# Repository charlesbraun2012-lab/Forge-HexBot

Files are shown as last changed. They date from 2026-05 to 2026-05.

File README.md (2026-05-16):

# Forge-HexBot
HexBot V2 (yes there was a v1 😭) is a mostly 3d printed 3d printer (only uses screws and threaded inserts but for v3 I plan to make it all press fit). This project is powered by: Forge, WhamBamSystems, and LDO Motors. This uses the open scource MKS tinybee board with TMC2209 with wifi integration. I plan to devlop a web app to utlise remote printing and controll. Additionally I plan to make an AMS style system that will be able to change colours wirelessly. (That is a seprate project) I made this project because I learned so much from V1 that I feel it wouldnt be right to not make anouther version.

V1:


V2 CAD:

Forge Printer _ V2 Assembily - Google Chrome 5_16_2026 5_11_53 PM

Wiring Diagram:

Untitled presentation (3)

Z-Axis

    Z-Axis motor $17 KB-3D Link
  
    M3 Nuts and bolts $10 Amazon Link
  
X-Axis

    E3D V6 Hot End $14 E3D V6 Hot End Link
  
    Extruder motor $17 KB-3D Link
  
    Extruder $6 Amazon Link
  
    X-Axis Motor$17KB-3D Link
  
    Pulleys $7 Amazon link
  
Y-Axis

    Y-axis motor $17 KB-3D Link
  
    Grease $8 Amazon Link
  
Electronics

    MKS TinyBee + screen + tmc drivers $59 Amazon Link
  
    Limit Switch $5 Amazon Link
  
    Wire Crimper & Connectors $30 Amazon Link
  
    Power supply $18 Amazon Link
  
    22 AWG wires $7 Amazon Link

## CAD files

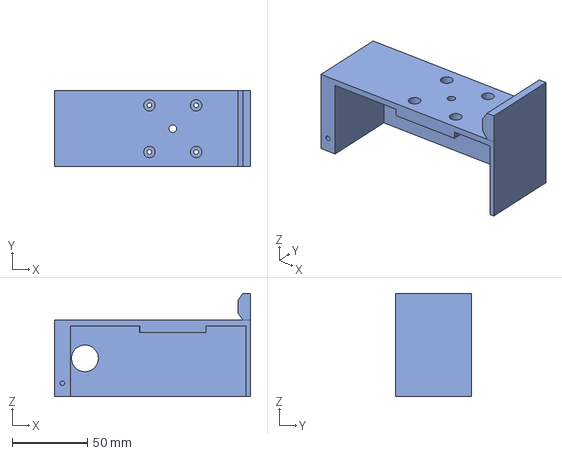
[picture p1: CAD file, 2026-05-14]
CAD/y-axis motor mount.step
130.1 x 50.3 x 68.6 mm

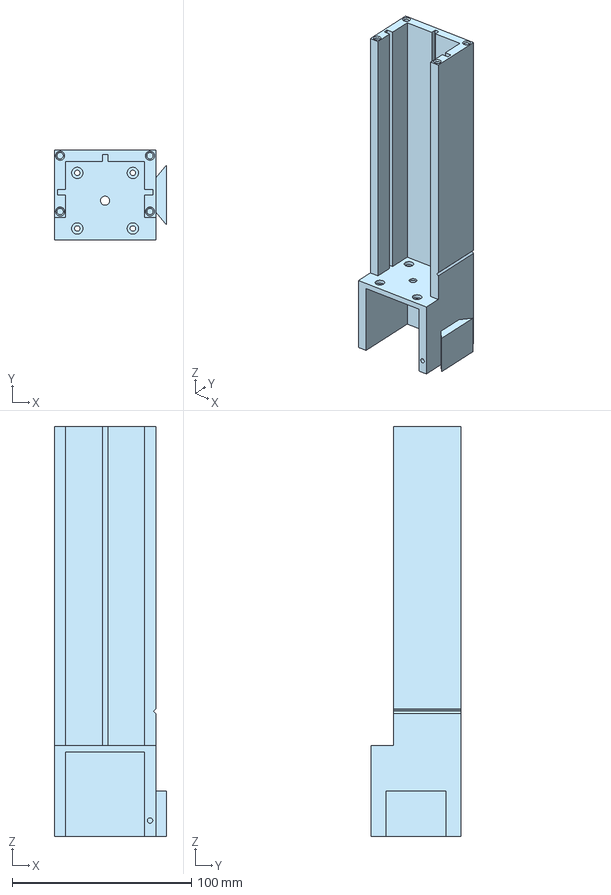
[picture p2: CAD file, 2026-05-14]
CAD/Z-Tower.step
62.7 x 50.3 x 228.6 mm

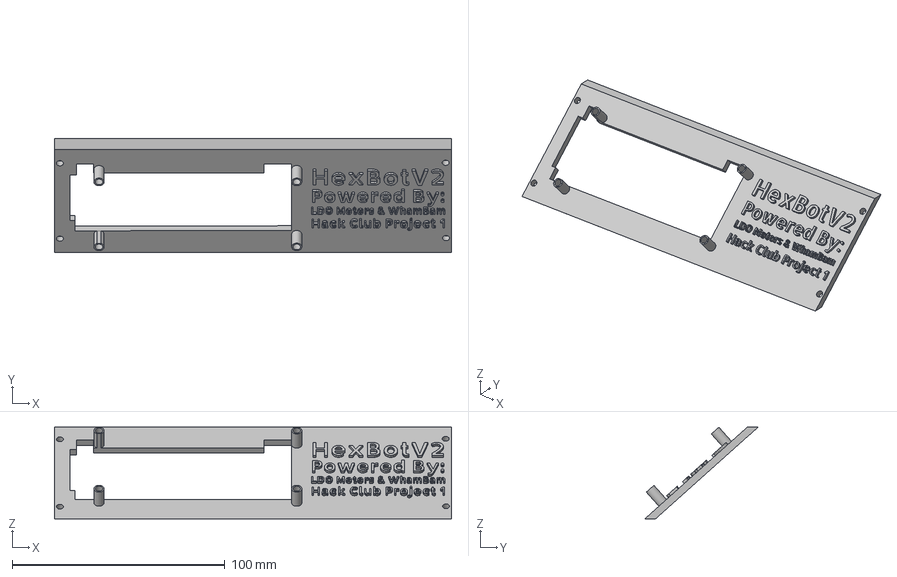
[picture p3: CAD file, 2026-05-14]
CAD/Front Base.step
186.7 x 53.4 x 43.2 mm

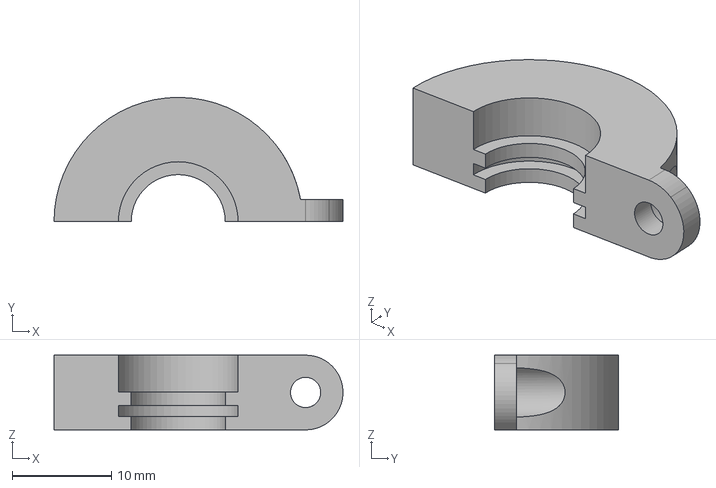
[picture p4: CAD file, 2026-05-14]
CAD/Extruder clamp.step
29.1 x 12.5 x 7.54 mm

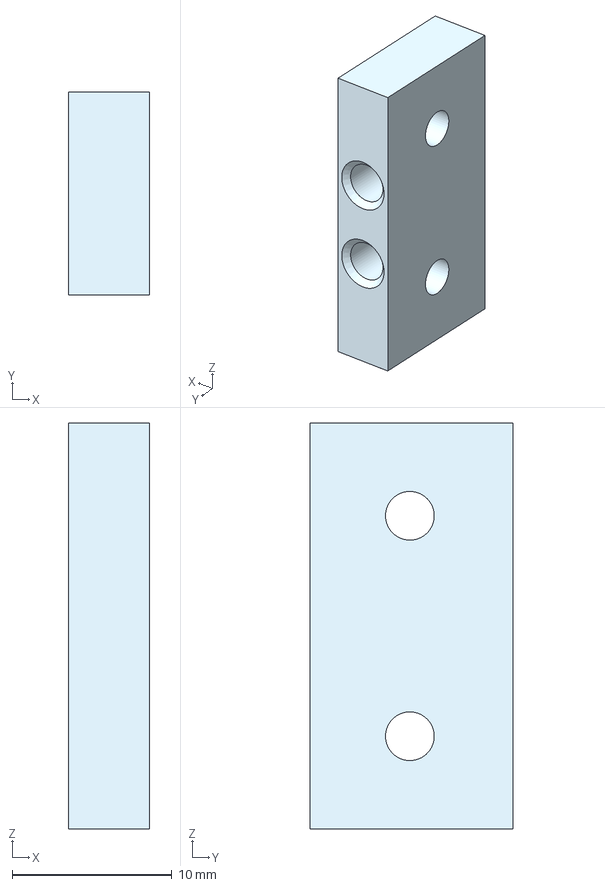
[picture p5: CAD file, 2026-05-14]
CAD/x-axis Idler tensioner.step
5.08 x 12.7 x 25.4 mm

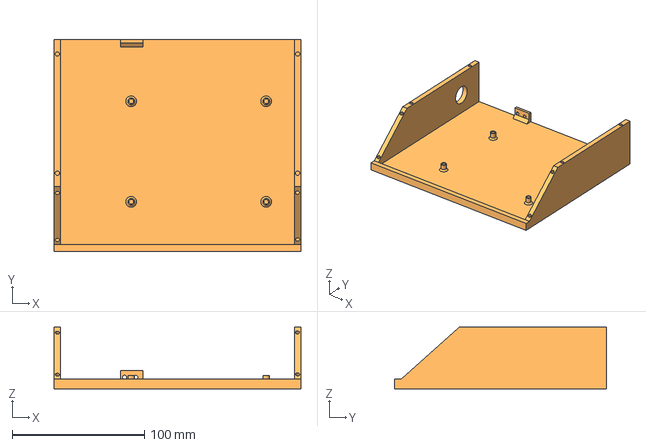
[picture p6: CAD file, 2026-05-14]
CAD/Base.step
186.7 x 160.0 x 46.9 mm

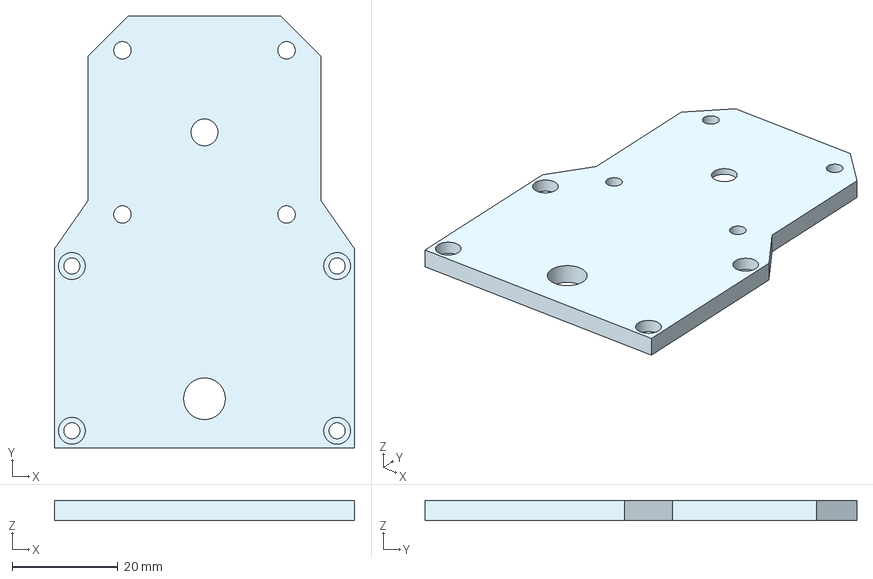
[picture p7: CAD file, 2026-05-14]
CAD/z-tower cap + extruder mount.step
56.6 x 81.6 x 3.81 mm

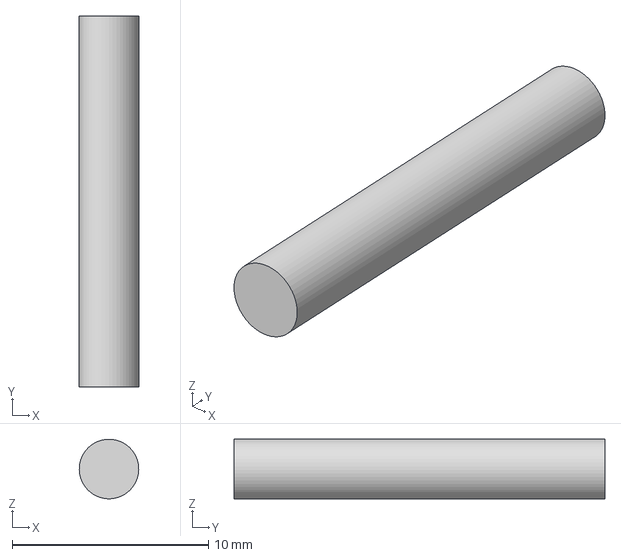
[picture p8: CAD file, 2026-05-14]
CAD/x-axis roller pin.step
3.04 x 18.9 x 3.04 mm

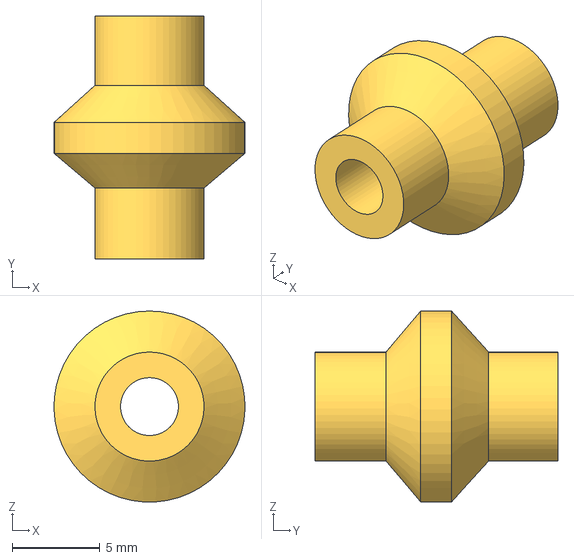
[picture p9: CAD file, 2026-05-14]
CAD/X-axis roller.step
10.9 x 13.8 x 10.9 mm

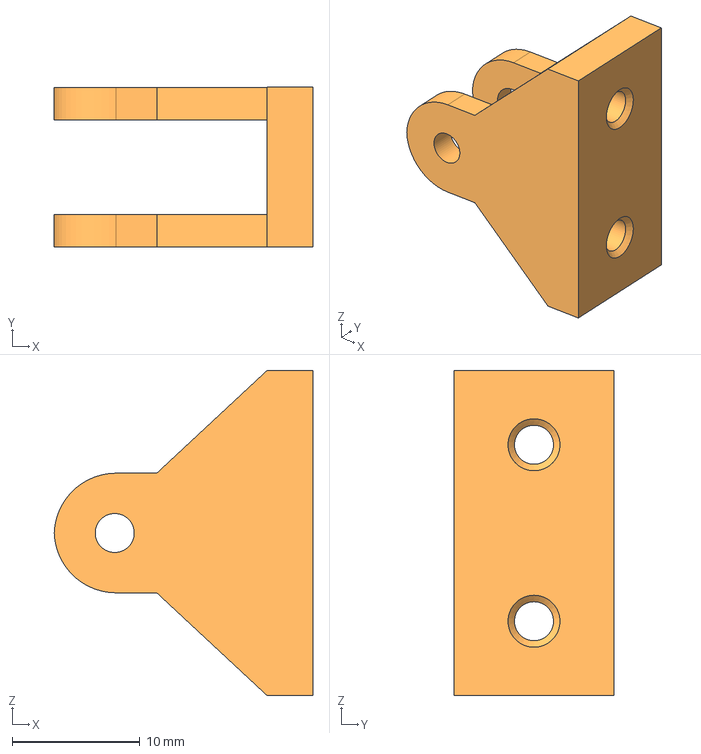
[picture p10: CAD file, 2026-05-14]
CAD/X-axis idler holder.step
20.2 x 12.5 x 25.4 mm

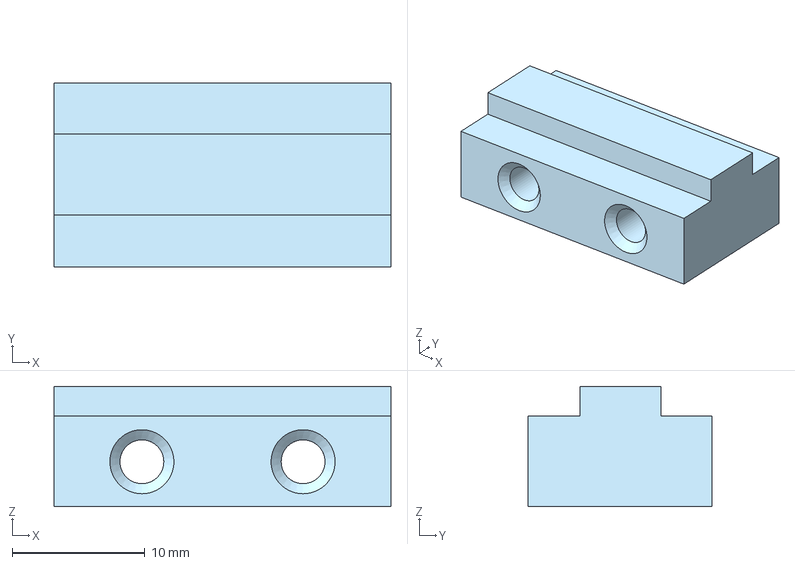
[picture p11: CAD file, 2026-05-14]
CAD/X-axis carriage bottom strengthener.step
25.4 x 13.9 x 9.05 mm

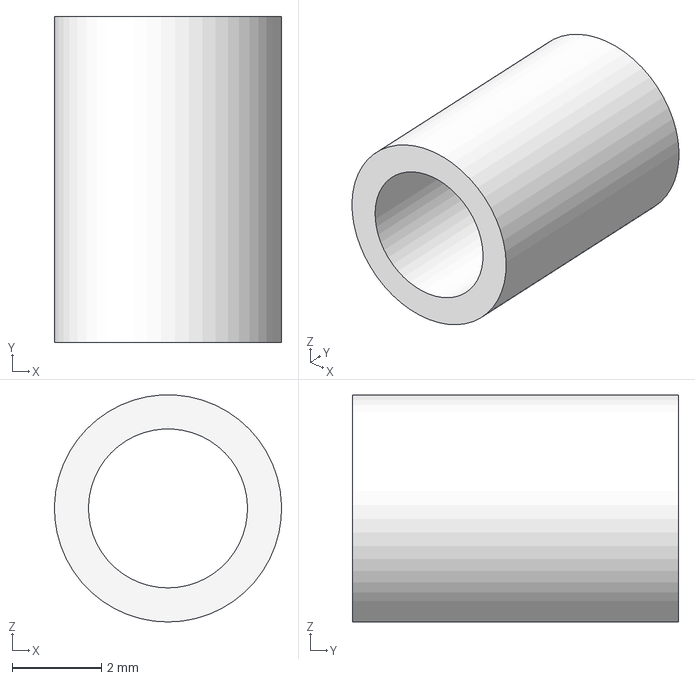
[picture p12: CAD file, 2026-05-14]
CAD/Idler pulley.step
5.08 x 7.29 x 5.08 mm

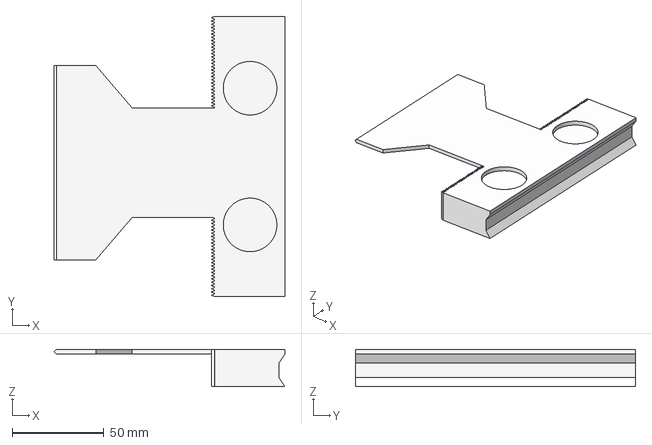
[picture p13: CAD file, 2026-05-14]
CAD/y-axis bed plate.step
125.8 x 152.5 x 20.3 mm

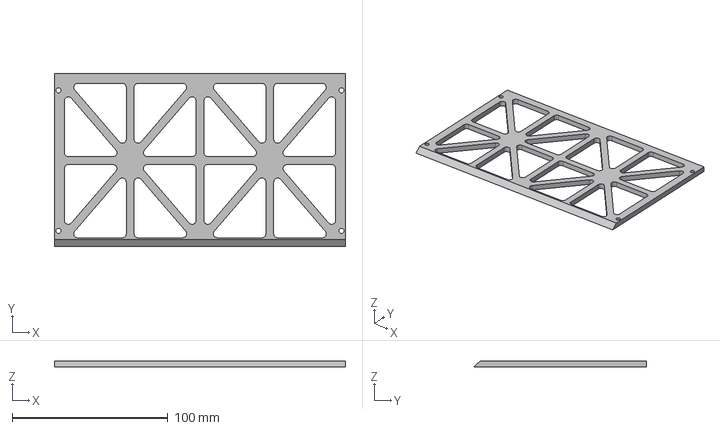
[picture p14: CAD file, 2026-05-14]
CAD/Base Top.step
186.7 x 111.0 x 3.94 mm

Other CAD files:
CAD/x-axis belt plate.step
CAD/Extruder holder plate (x carrage).step
CAD/y-axis gear.step
CAD/X-Axis arm.step
CAD/Z-Axis Nut - carrage.step
CAD/Z-tower lead screw.step

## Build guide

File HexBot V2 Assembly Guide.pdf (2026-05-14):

# HexBot V2 Assembly Guide

## Open Source created by Charles Braun under MIT License

## Z-Axis

Parts Needed:

1x lead screw (Printed at 96% scale on x and y axis, print test piece to find optimal sale)

1 Lead Screw housing

1x Lead Screw bearing block

1x Lead screw cap & extruder mount

1x Stepper Motor (Nema 17)

9x M3 heat set inserts

8x M3 screws

## Step 1:

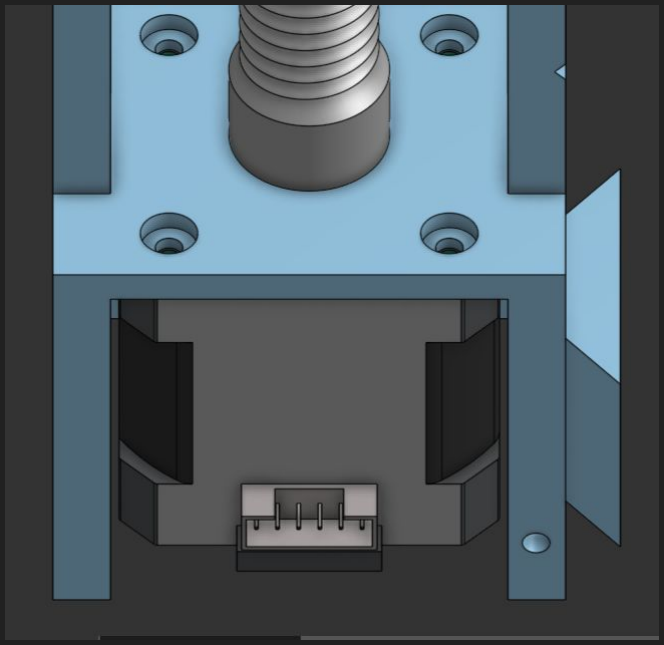
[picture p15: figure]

Take the Nema 17 and screw it in.

Make sure the connector/wires are facing out.

## Step 2:

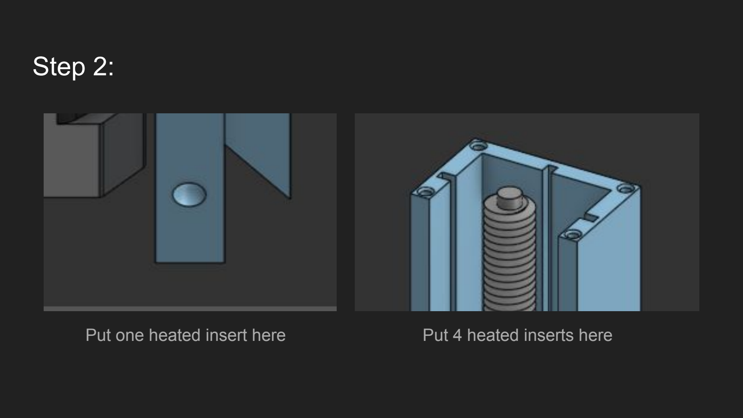
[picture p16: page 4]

Put one heated insert here | Put 4 heated inserts here

## Step 3:

Slide Lead screw onto the
Nema 17 shaft.

## Step 4:

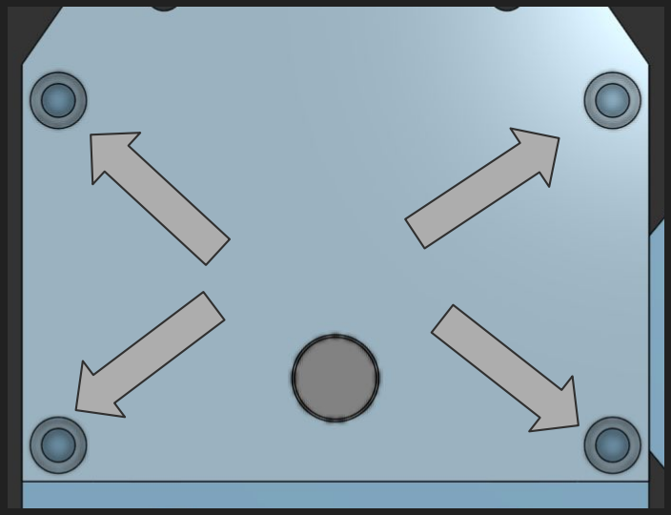
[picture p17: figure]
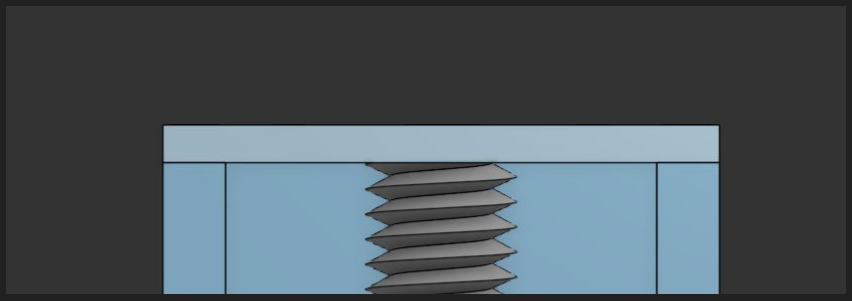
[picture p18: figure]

Put an M3 screw into the threaded insert with the lead screw top in the middle of the screw head and the insert.

## Step 5:

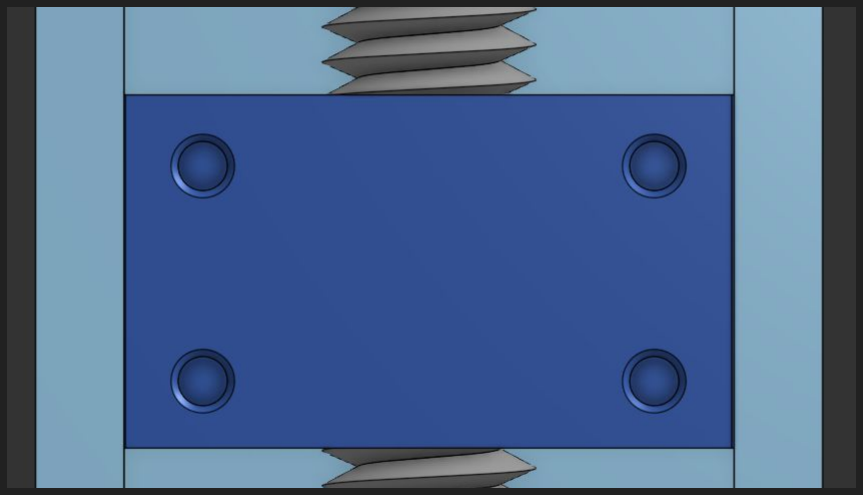
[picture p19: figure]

Put one M3 heat insert in each of the 4 holes

## Step 6:

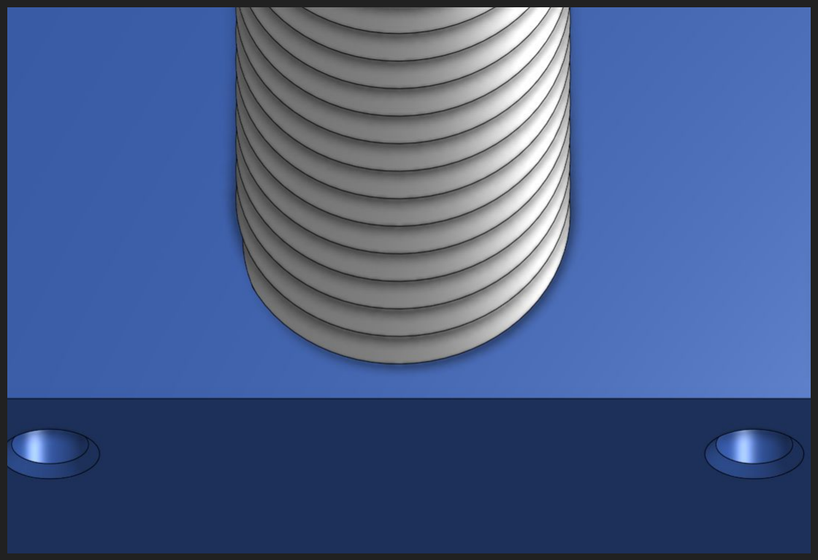
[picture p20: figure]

Screw the lead screw into the lead screw bearing block

## X-Axis

Parts Needed:

1x Main Arm

1x Idler Holder

1x Idler tensioner

1x Belt Plate

1x Hotend Plate

2x rollers

1x bottom holder

1x Stepper Motor (Nema 17)

10x M3 heat set inserts

8x M3 screws

1x pulley & idler

1x 1 Meter GT2 timing belt

2x Pins for rollers

## Step 1:

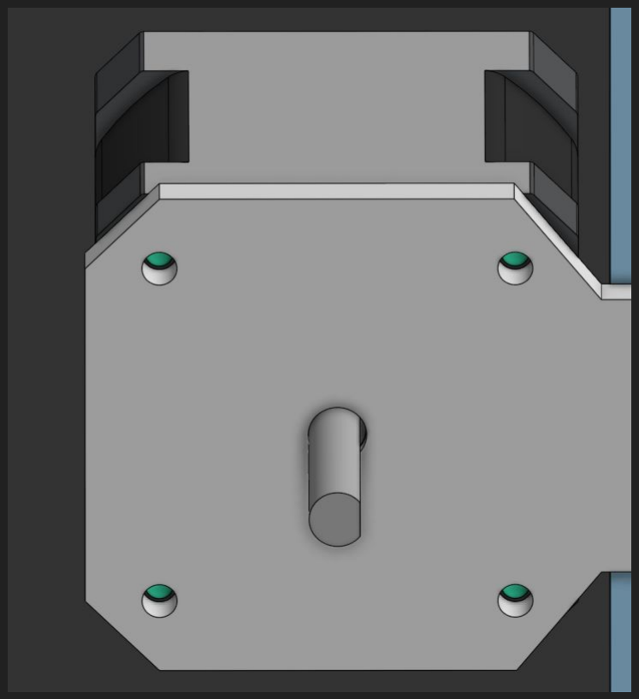
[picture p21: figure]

Screw the Nema 17 into the far left end of the arm

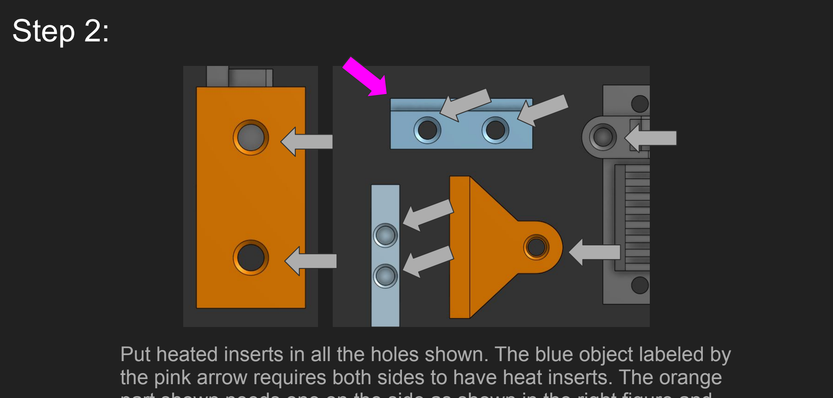
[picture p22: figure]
Step 2:

Put heated inserts in all the holes shown. The blue object labeled by the pink arrow requires both sides to have heat inserts. The orange part shown needs one on the side as shown in the right figure and two in the back as shown in the left.

## Step 3:

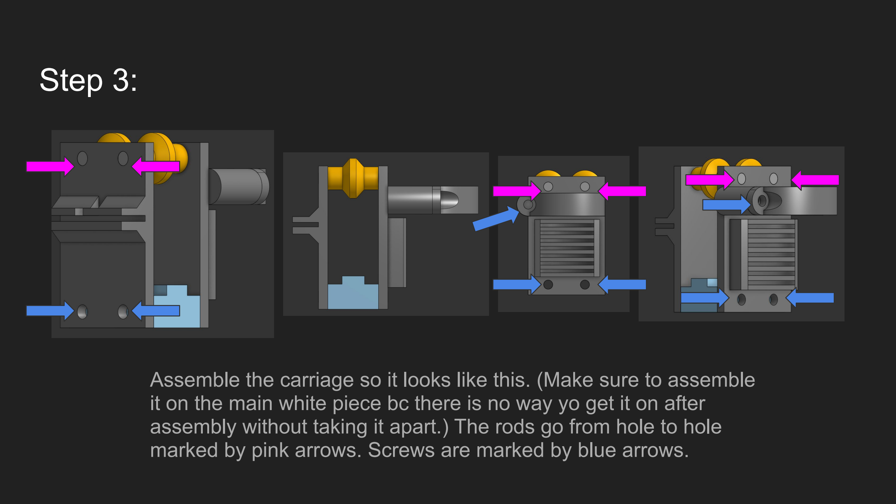
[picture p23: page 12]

Assemble the carriage so it looks like this. (Make sure to assemble it on the main white piece bc there is no way yo get it on after assembly without taking it apart.) The rods go from hole to hole marked by pink arrows. Screws are marked by blue arrows.

## Step 4:

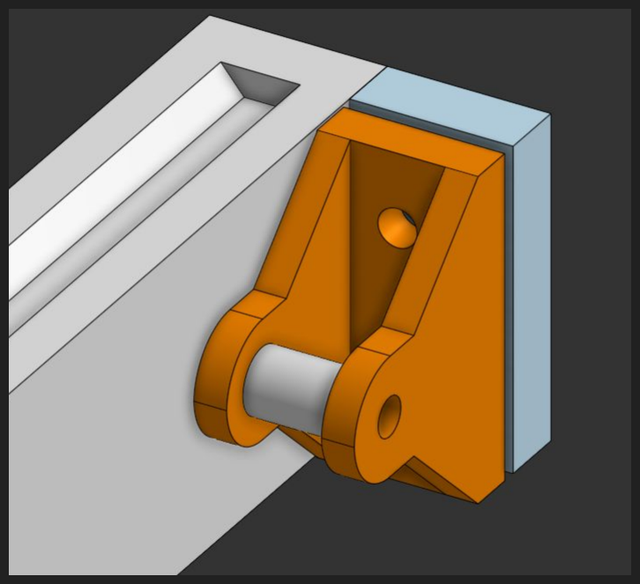
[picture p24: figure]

Take the idler holder (orange) and put the idler (White tube) in the middle of the hole. Put a M3 screw into the front side and screw until it reaches the heat insert in the back side.

Take the idler tensioner
block (light blue) and put a screw through the rail
(white)

## Step 5:

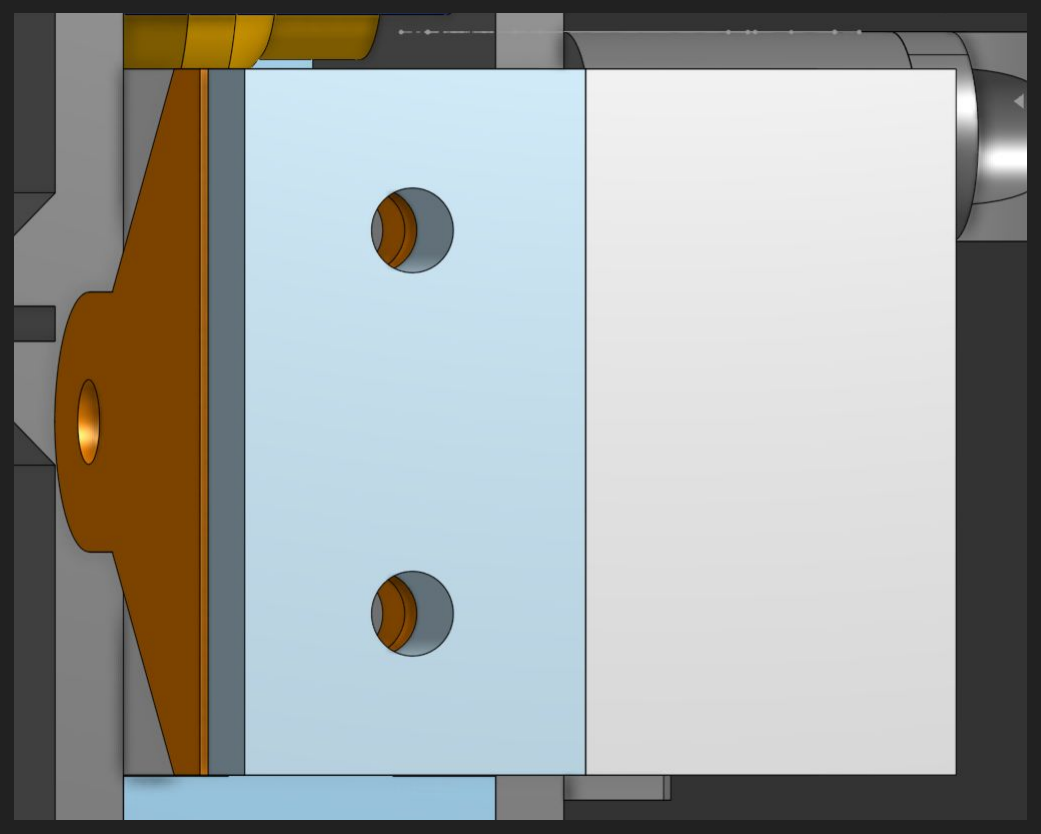
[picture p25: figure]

Put a screw through each hole on the light blue part and make sure it touches the threaded insert in the orange part. To tension the belt just turn the screws right.

## Step 6:

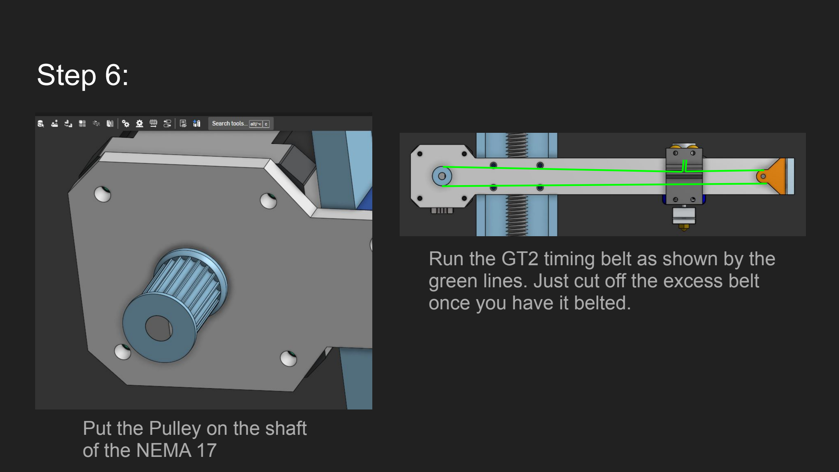
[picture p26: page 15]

Put the Pulley on the shaft of the NEMA 17

Run the GT2 timing belt as shown by the green lines. Just cut off the excess belt once you have it belted.

Y-Axis | Parts Needed:

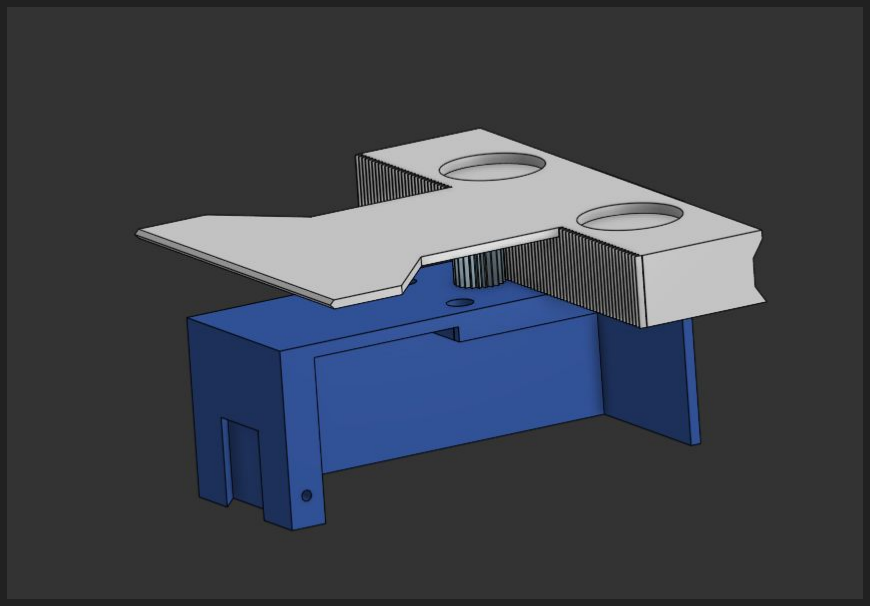
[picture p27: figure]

| 1x Y-Motor mount
| 1x Bed Platform
| 1x Gear
| 1x Nema 17
| 1x heat insert
| 1x 165x165 build plate (can be 3d printed as long as painters tape is applied to the top)
| Optional :
| 2x Magnets less than 0.11 in tall

## Step 1:

Screw the NEMA 17 in.
(Make sure the screws are
either flush or below the
top because that can lead
to interference.

## Step 2:

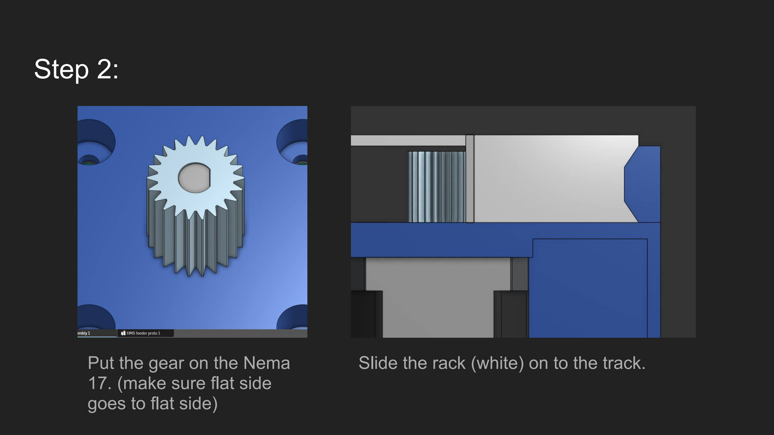
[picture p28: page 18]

Put the gear on the Nema
17. (make sure flat side
goes to flat side)

Slide the rack (white) on to the track.

## Step 3: (Optional)

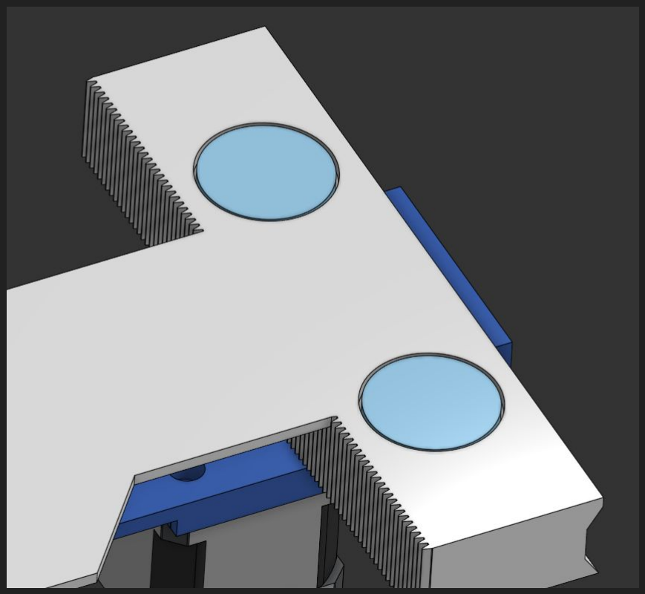
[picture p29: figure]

Put 2 magnets in the slots. No taller than 0.11 in (2.8mm) and no wider than 1.1 in (28mm) just use hot glue or sum to attach.

Base | Parts Needed:
| 1x front plate
| 1x top plate
| 1x base tray
| 1x MKS Mini12864 V3 (screen)
| 1x MKS TinyBee V1.0 (Board)
| 16x heat insert

## Step 1:

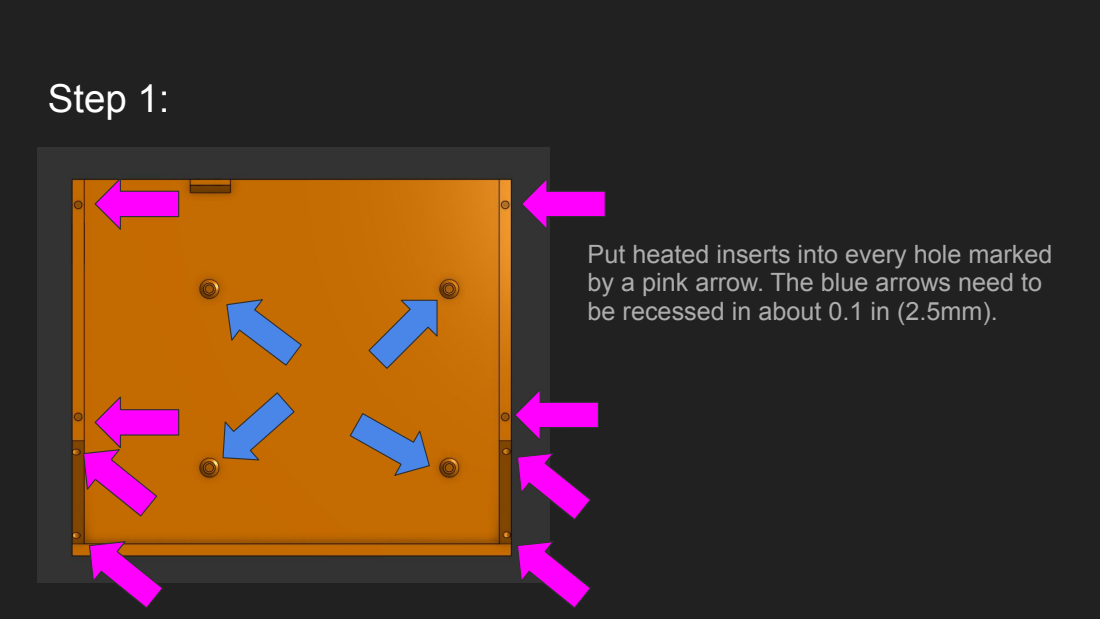
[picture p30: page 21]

Put heated inserts into every hole marked
by a pink arrow. The blue arrows need to
be recessed in about 0.1 in (2.5mm).

## Step 2:

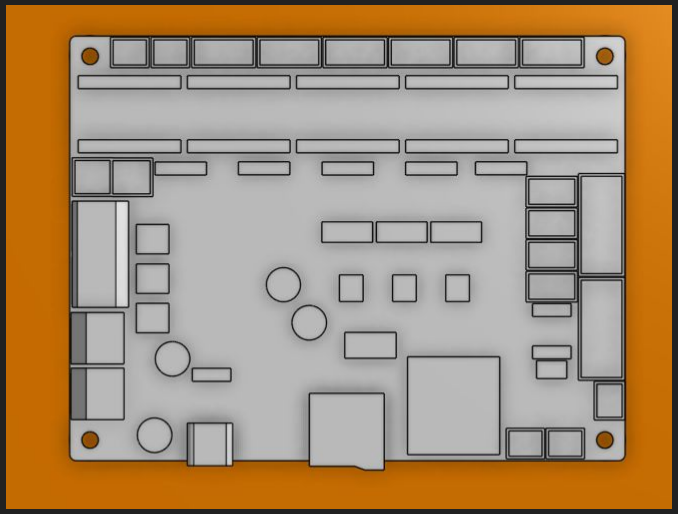
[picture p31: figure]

Put the MKS tinybee on. (Do Not overtighten bc I dont want u to break the board)

## Step 3:

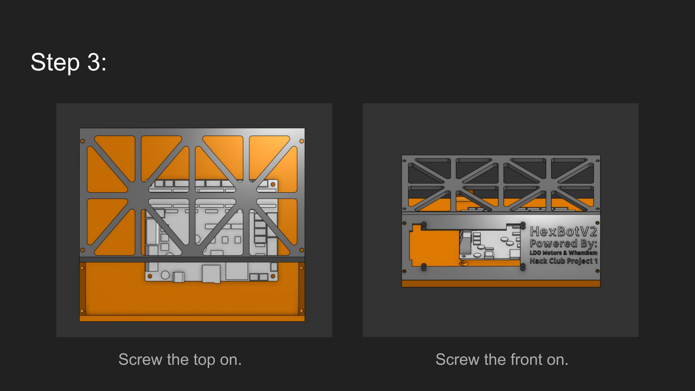
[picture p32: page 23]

Screw the top on. | Screw the front on.

## Step 4:

Put heated inserts where the blue arrows are

Screw the screen in (do not overtighten)

## Extruder

Parts Needed:

1x Nema 17

1x Bowden extruder (Ender 3) kit

1x Bowden tubing

## Step 1:

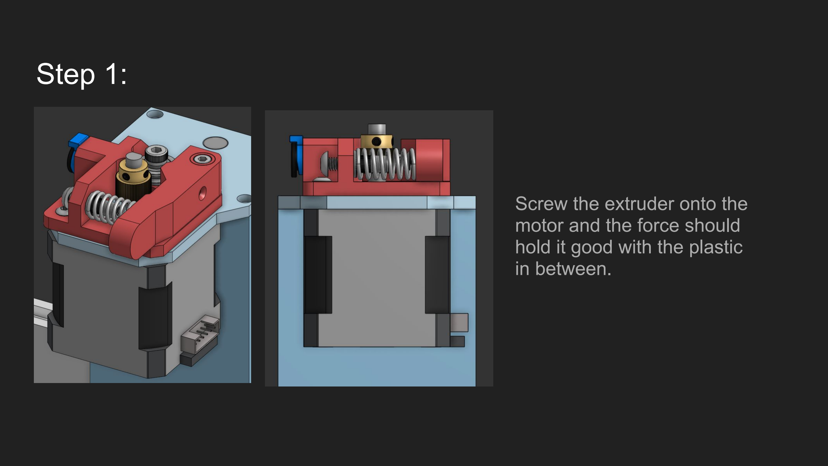
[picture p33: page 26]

Screw the extruder onto the motor and the force should hold it good with the plastic in between.

## Step 2:

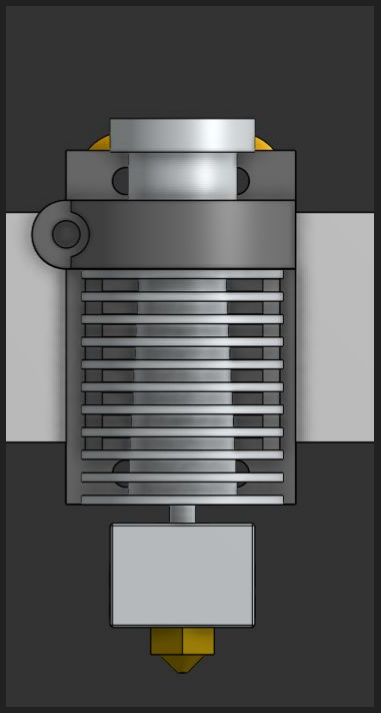
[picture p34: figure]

Screw the screw marked by
the blue arrow to clamp in the hotend.

## Final assembly

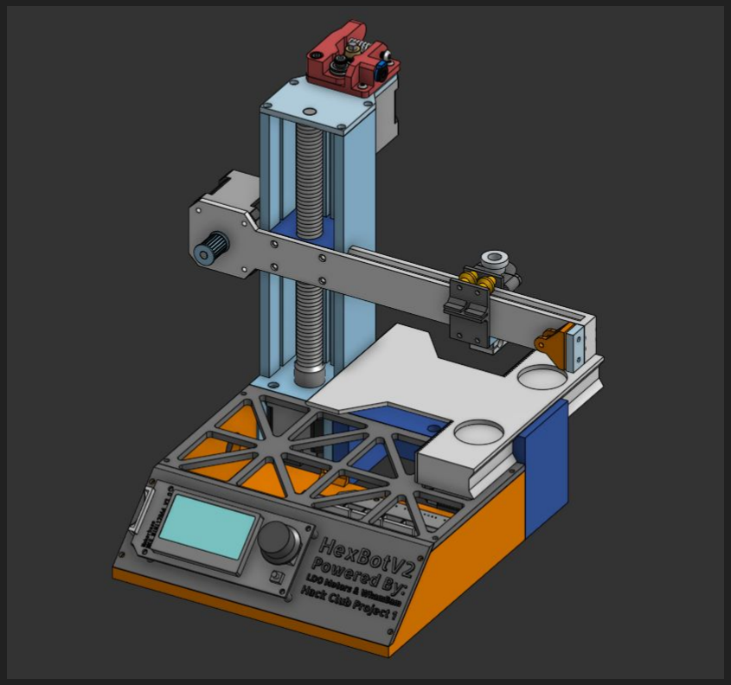
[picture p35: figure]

Parts Needed:

1x X-axis

1x Z-Tower

1x Y-axis

1x Base

## Step 1:

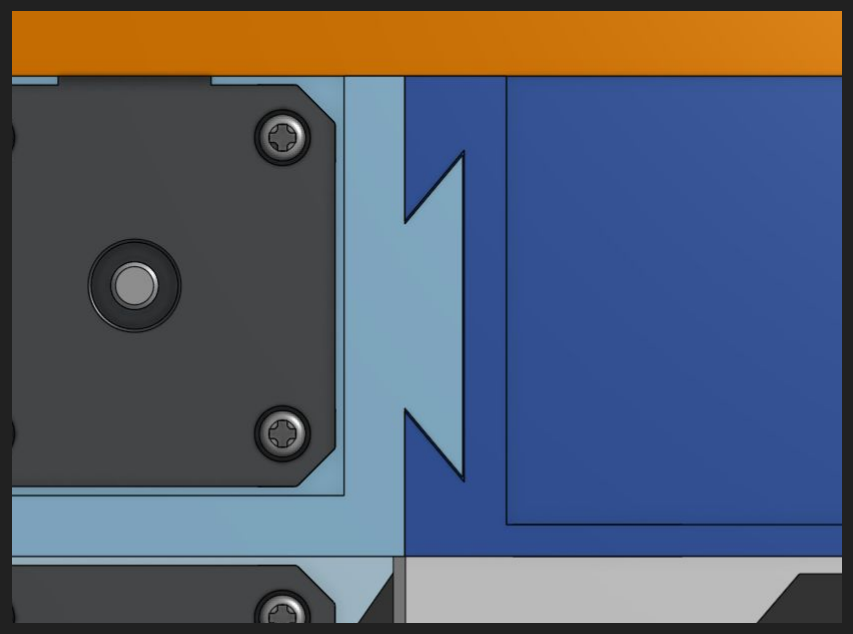
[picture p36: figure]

Connect the dovetail of the Z-Tower (light blue) and the Y-Axis motor mount (blue)

Screw these 4 holes in. If additional support is needed super glue will work or you can hot glue/ filament weld.

## Step 2:

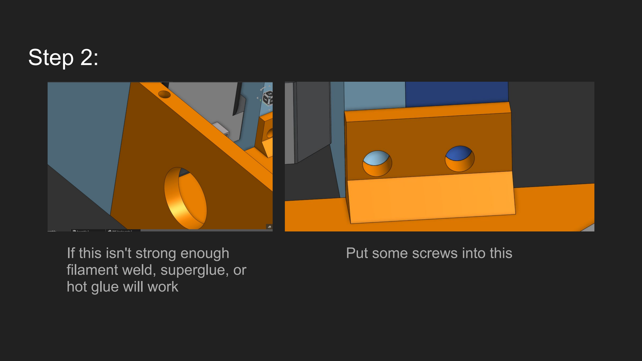
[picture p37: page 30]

If this isn't strong enough filament weld, superglue, or hot glue will work

Put some screws into this

## Step 3:

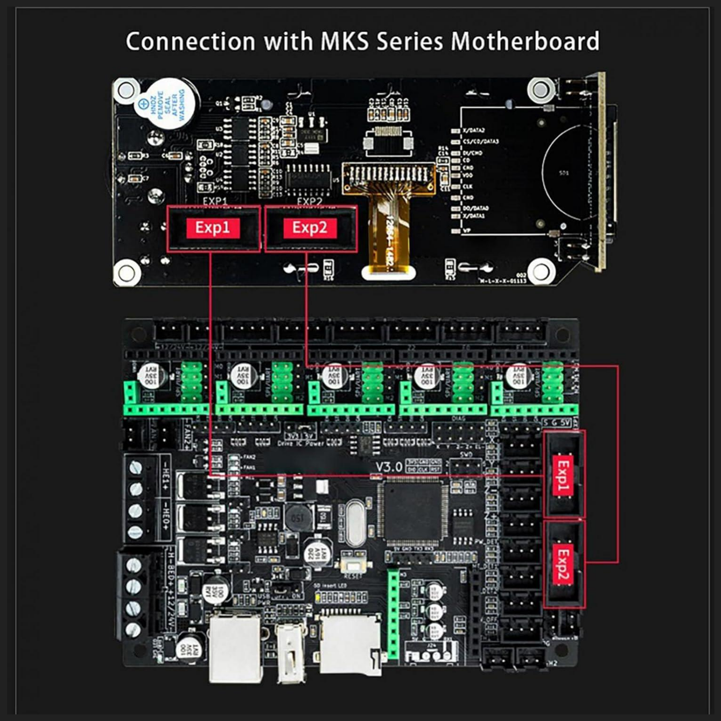
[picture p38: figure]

Wire everything up.

### Watch a youtube tutorial if ur stuck. Good luck Full BOM available on GitHub!

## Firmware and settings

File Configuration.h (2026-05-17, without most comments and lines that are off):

#pragma once
#define CONFIGURATION_H_VERSION 02000902
#define STRING_CONFIG_H_AUTHOR "(none, default config)" // Who made the changes.
#define SHOW_BOOTSCREEN
#define SERIAL_PORT 0
#define BAUDRATE 115200
#define SERIAL_PORT_2 -1
#define BAUDRATE_2 115200   // Enable to override BAUDRATE
  #define MOTHERBOARD BOARD_MKS_TINYBEE
#if LINEAR_AXES >= 4
  #define AXIS4_NAME 'A' // :['A', 'B', 'C', 'U', 'V', 'W']
#endif
#if LINEAR_AXES >= 5
  #define AXIS5_NAME 'B' // :['A', 'B', 'C', 'U', 'V', 'W']
#endif
#if LINEAR_AXES >= 6
  #define AXIS6_NAME 'C' // :['A', 'B', 'C', 'U', 'V', 'W']
#endif
#define EXTRUDERS 1
#define DEFAULT_NOMINAL_FILAMENT_DIA 1.75
#define TEMP_SENSOR_0 1
#define TEMP_SENSOR_1 0
#define TEMP_SENSOR_2 0
#define TEMP_SENSOR_3 0
#define TEMP_SENSOR_4 0
#define TEMP_SENSOR_5 0
#define TEMP_SENSOR_6 0
#define TEMP_SENSOR_7 0
#define TEMP_SENSOR_BED 0
#define TEMP_SENSOR_PROBE 0
#define TEMP_SENSOR_CHAMBER 0
#define TEMP_SENSOR_COOLER 0
#define TEMP_SENSOR_BOARD 0
#define TEMP_SENSOR_REDUNDANT 0
#define DUMMY_THERMISTOR_998_VALUE  25
#define DUMMY_THERMISTOR_999_VALUE 100
#define TEMP_RESIDENCY_TIME         10  // (seconds) Time to wait for hotend to "settle" in M109
#define TEMP_WINDOW                  1  // (°C) Temperature proximity for the "temperature reached" timer
#define TEMP_HYSTERESIS              3  // (°C) Temperature proximity considered "close enough" to the target
#define TEMP_BED_RESIDENCY_TIME     10  // (seconds) Time to wait for bed to "settle" in M190
#define TEMP_BED_WINDOW              1  // (°C) Temperature proximity for the "temperature reached" timer
#define TEMP_BED_HYSTERESIS          3  // (°C) Temperature proximity considered "close enough" to the target
#define TEMP_CHAMBER_RESIDENCY_TIME 10  // (seconds) Time to wait for chamber to "settle" in M191
#define TEMP_CHAMBER_WINDOW          1  // (°C) Temperature proximity for the "temperature reached" timer
#define TEMP_CHAMBER_HYSTERESIS      3  // (°C) Temperature proximity considered "close enough" to the target
#if TEMP_SENSOR_REDUNDANT
  #define TEMP_SENSOR_REDUNDANT_SOURCE    E1  // The sensor that will provide the redundant reading.
  #define TEMP_SENSOR_REDUNDANT_TARGET    E0  // The sensor that we are providing a redundant reading for.
  #define TEMP_SENSOR_REDUNDANT_MAX_DIFF  10  // (°C) Temperature difference that will trigger a print abort.
#endif
#define HEATER_0_MINTEMP   5
#define HEATER_1_MINTEMP   5
#define HEATER_2_MINTEMP   5
#define HEATER_3_MINTEMP   5
#define HEATER_4_MINTEMP   5
#define HEATER_5_MINTEMP   5
#define HEATER_6_MINTEMP   5
#define HEATER_7_MINTEMP   5
#define BED_MINTEMP        5
#define CHAMBER_MINTEMP    5
#define HEATER_0_MAXTEMP 275
#define HEATER_1_MAXTEMP 275
#define HEATER_2_MAXTEMP 275
#define HEATER_3_MAXTEMP 275
#define HEATER_4_MAXTEMP 275
#define HEATER_5_MAXTEMP 275
#define HEATER_6_MAXTEMP 275
#define HEATER_7_MAXTEMP 275
#define BED_MAXTEMP      150
#define CHAMBER_MAXTEMP  60
#define HOTEND_OVERSHOOT 15   // (°C) Forbid temperatures over MAXTEMP - OVERSHOOT
#define BED_OVERSHOOT    10   // (°C) Forbid temperatures over MAXTEMP - OVERSHOOT
#define COOLER_OVERSHOOT  2   // (°C) Forbid temperatures closer than OVERSHOOT
#define PIDTEMP
#define BANG_MAX 255     // Limits current to nozzle while in bang-bang mode; 255=full current
#define PID_MAX BANG_MAX // Limits current to nozzle while PID is active (see PID_FUNCTIONAL_RANGE below); 255=full current
#define PID_K1 0.95      // Smoothing factor within any PID loop
    #define DEFAULT_Kp  22.20
    #define DEFAULT_Ki   1.08
    #define DEFAULT_Kd 114.00
#define MAX_BED_POWER 255 // limits duty cycle to bed; 255=full current
#define MAX_CHAMBER_POWER 255 // limits duty cycle to chamber heater; 255=full current
  #define PID_FUNCTIONAL_RANGE 10 // If the temperature difference between the target temperature and the actual temperature
#define PREVENT_COLD_EXTRUSION
#define EXTRUDE_MINTEMP 170
#define PREVENT_LENGTHY_EXTRUDE
#define EXTRUDE_MAXLENGTH 200
#define THERMAL_PROTECTION_HOTENDS // Enable thermal protection for all extruders
#define THERMAL_PROTECTION_BED     // Enable thermal protection for the heated bed
#define THERMAL_PROTECTION_CHAMBER // Enable thermal protection for the heated chamber
#define THERMAL_PROTECTION_COOLER  // Enable thermal protection for the laser cooling
#define USE_XMIN_PLUG
#define USE_YMIN_PLUG
#define USE_ZMIN_PLUG
#define ENDSTOPPULLUPS
#define X_MIN_ENDSTOP_INVERTING true // Set to true to invert the logic of the endstop.
#define Y_MIN_ENDSTOP_INVERTING true // Set to true to invert the logic of the endstop.
#define Z_MIN_ENDSTOP_INVERTING true // Set to true to invert the logic of the endstop.
#define I_MIN_ENDSTOP_INVERTING false // Set to true to invert the logic of the endstop.
#define J_MIN_ENDSTOP_INVERTING false // Set to true to invert the logic of the endstop.
#define K_MIN_ENDSTOP_INVERTING false // Set to true to invert the logic of the endstop.
#define X_MAX_ENDSTOP_INVERTING false // Set to true to invert the logic of the endstop.
#define Y_MAX_ENDSTOP_INVERTING false // Set to true to invert the logic of the endstop.
#define Z_MAX_ENDSTOP_INVERTING false // Set to true to invert the logic of the endstop.
#define I_MAX_ENDSTOP_INVERTING false // Set to true to invert the logic of the endstop.
#define J_MAX_ENDSTOP_INVERTING false // Set to true to invert the logic of the endstop.
#define K_MAX_ENDSTOP_INVERTING false // Set to true to invert the logic of the endstop.
#define Z_MIN_PROBE_ENDSTOP_INVERTING false // Set to true to invert the logic of the probe.
#define X_DRIVER_TYPE  TMC2209_STANDALONE
#define Y_DRIVER_TYPE  TMC2209_STANDALONE
#define Z_DRIVER_TYPE  TMC2209_STANDALONE
#define E0_DRIVER_TYPE TMC2209_STANDALONE
#define DEFAULT_AXIS_STEPS_PER_UNIT   { 80, 92.59, 1259.84, 400 }
#define DEFAULT_MAX_FEEDRATE          { 300, 300, 5, 25 }
#define DEFAULT_MAX_ACCELERATION      { 200, 200, 50, 500 }
#define DEFAULT_ACCELERATION          200    // X, Y, Z and E acceleration for printing moves
#define DEFAULT_RETRACT_ACCELERATION  500    // E acceleration for retracts
#define DEFAULT_TRAVEL_ACCELERATION   500    // X, Y, Z acceleration for travel (non printing) moves
#define DEFAULT_EJERK    5.0  // May be used by Linear Advance
  #define JUNCTION_DEVIATION_MM 0.013 // (mm) Distance from real junction edge
  #define JD_HANDLE_SMALL_SEGMENTS    // Use curvature estimation instead of just the junction angle
#define Z_MIN_PROBE_USES_Z_MIN_ENDSTOP_PIN
#define NOZZLE_TO_PROBE_OFFSET { 10, 10, 0 }
#define PROBING_MARGIN 10
#define XY_PROBE_FEEDRATE (133*60)
#define Z_PROBE_FEEDRATE_FAST (4*60)
#define Z_PROBE_FEEDRATE_SLOW (Z_PROBE_FEEDRATE_FAST / 2)
#define Z_CLEARANCE_DEPLOY_PROBE   10 // Z Clearance for Deploy/Stow
#define Z_CLEARANCE_BETWEEN_PROBES  5 // Z Clearance between probe points
#define Z_CLEARANCE_MULTI_PROBE     5 // Z Clearance between multiple probes
#define Z_PROBE_LOW_POINT          -2 // Farthest distance below the trigger-point to go before stopping
#define Z_PROBE_OFFSET_RANGE_MIN -20
#define Z_PROBE_OFFSET_RANGE_MAX 20
#define X_ENABLE_ON 0
#define Y_ENABLE_ON 0
#define Z_ENABLE_ON 0
#define E_ENABLE_ON 0 // For all extruders
#define DISABLE_X false
#define DISABLE_Y false
#define DISABLE_Z false
#define DISABLE_E false             // Disable the extruder when not stepping
#define DISABLE_INACTIVE_EXTRUDER   // Keep only the active extruder enabled
#define INVERT_X_DIR false
#define INVERT_Y_DIR false
#define INVERT_Z_DIR false
#define INVERT_E0_DIR false
#define INVERT_E1_DIR false
#define INVERT_E2_DIR false
#define INVERT_E3_DIR false
#define INVERT_E4_DIR false
#define INVERT_E5_DIR false
#define INVERT_E6_DIR false
#define INVERT_E7_DIR false
#define X_HOME_DIR -1
#define Y_HOME_DIR -1
#define Z_HOME_DIR -1
#define X_BED_SIZE 130
#define Y_BED_SIZE 140
#define X_MIN_POS 0
#define Y_MIN_POS 0
#define Z_MIN_POS 0
#define X_MAX_POS X_BED_SIZE
#define Y_MAX_POS Y_BED_SIZE
#define Z_MAX_POS 115
#define MIN_SOFTWARE_ENDSTOPS
  #define MIN_SOFTWARE_ENDSTOP_X
  #define MIN_SOFTWARE_ENDSTOP_Y
  #define MIN_SOFTWARE_ENDSTOP_Z
  #define MIN_SOFTWARE_ENDSTOP_I
  #define MIN_SOFTWARE_ENDSTOP_J
  #define MIN_SOFTWARE_ENDSTOP_K
#define MAX_SOFTWARE_ENDSTOPS
  #define MAX_SOFTWARE_ENDSTOP_X
  #define MAX_SOFTWARE_ENDSTOP_Y
  #define MAX_SOFTWARE_ENDSTOP_Z
  #define MAX_SOFTWARE_ENDSTOP_I
  #define MAX_SOFTWARE_ENDSTOP_J
  #define MAX_SOFTWARE_ENDSTOP_K
#define HOMING_FEEDRATE_MM_M { (50*60), (50*60), (4*60) }
#define VALIDATE_HOMING_ENDSTOPS
#define EEPROM_SETTINGS     // Persistent storage with M500 and M501
#define EEPROM_CHITCHAT       // Give feedback on EEPROM commands. Disable to save PROGMEM.
#define EEPROM_BOOT_SILENT    // Keep M503 quiet and only give errors during first load
  #define EEPROM_AUTO_INIT  // Init EEPROM automatically on any errors.
#define HOST_KEEPALIVE_FEATURE        // Disable this if your host doesn't like keepalive messages
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

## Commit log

2026-04-18 Create CAD Files
2026-04-18 Create Bill Of Materials (Not Final)
2026-05-13 Updated BOM
2026-05-13 Update CAD Files
2026-05-14 HexBot Assembly Guide PDF
2026-05-14 CAD Files
    [Base Top.step, Base.step, Extruder clamp.step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]
2026-05-14 Bill Of Materials
2026-05-16 Update Bill Of Materials
2026-10-31 Fix formatting in Y-Axis section of README
2026-10-31 Rename Bill Of Materials to BOM.csv
2026-10-31 Add firmware information for MKS Tinybee printer

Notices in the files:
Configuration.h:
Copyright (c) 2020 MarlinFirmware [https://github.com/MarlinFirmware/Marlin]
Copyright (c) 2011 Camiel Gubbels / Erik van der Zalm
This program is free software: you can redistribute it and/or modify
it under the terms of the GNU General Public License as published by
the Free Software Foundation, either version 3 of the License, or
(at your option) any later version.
